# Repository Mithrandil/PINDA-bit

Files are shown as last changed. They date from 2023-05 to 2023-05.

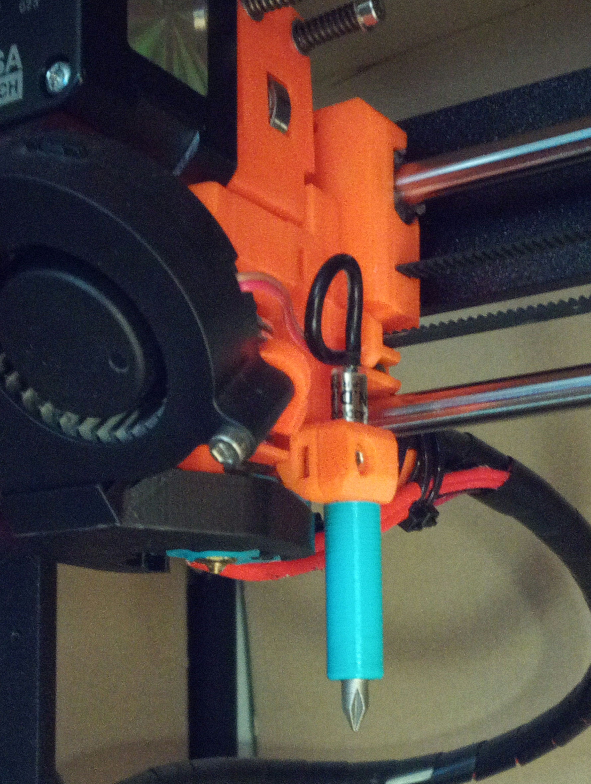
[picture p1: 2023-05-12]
PINDA-bit.jpg

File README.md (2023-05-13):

# PINDA-bit

3D Printed Bit Holder for High-Resolution Heatbed Scanning

This is a simple and useful accessory for Prusa MK2 and MK2S 3D printers (or other printers with an inductive probe). It is a plastic tube that holds a screwdriver bit and allows you to scan the MK42 heatbed with the P.I.N.D.A sensor. This way, you can level the bed for non-magnetic or off-magnet print surfaces.

The advantage of using this accessory is that you can perform finer mesh bed leveling with a 7x7 grid or any arbitrary resolution. This can improve the first layer quality and adhesion on uneven or warped beds. Moreover, since the shape of the MK42 heatbed depends only on the temperature and is consistent between prints, you don't need to scan the bed every time you change the print surface, as long as you use the same temperature. You can also save different presets of the bed mesh for different temperatures and recall them when needed.

However, to scan a print surface that is outside of the magnet points, you need to use custom firmware such as Klipper. You can find an MK2s config here: https://github.com/Mithrandil/klipper-config-prusa-mk2s

In this repository, you will find a module that corrects the tilt of the X-axis before each print. This is necessary because the position of the Z-axis motors is not preserved between prints when they are not powered. Therefore, if you use this accessory to scan a non-magnetic print surface, you need to run this module before printing to ensure a level bed.

# HOW TO USE:

The accessory is easy to use: just insert the bit into the tube and place it on the P.I.N.D.A sensor. The tube should protrude much more than the nozzle so that it can reach the print surface without touching it. Then, run a custom G-code macro to perform a mesh bed leveling with your desired resolution. You can save the mesh in your configuration file for future prints (after removing the tube).

G-Code macro for scanning and saving the high-resolution bed mesh with the accessory at a given temperature:

For 60°C heated bed (accessory mounted):

CREATE_AND_SAVE_NEW_MESH S60; [60 = first_layer_bed_temperature]

For using the saved mesh corrected with a new one (before each print, no accessory mounted):

BED_MESH_CALIBRATE; mesh bed leveling

BED_TILT_CORRECTION SAVEDMESH=MESH60; [60 = first_layer_bed_temperature]

The accessory is also easy to print: it doesn't require any supports or infill, and it takes less than 10 minutes to print. You should use a filament that can withstand high temperatures and does not deform easily, such as PETG or ASA. These filaments are especially recommended if you use an enclosure for your printer.

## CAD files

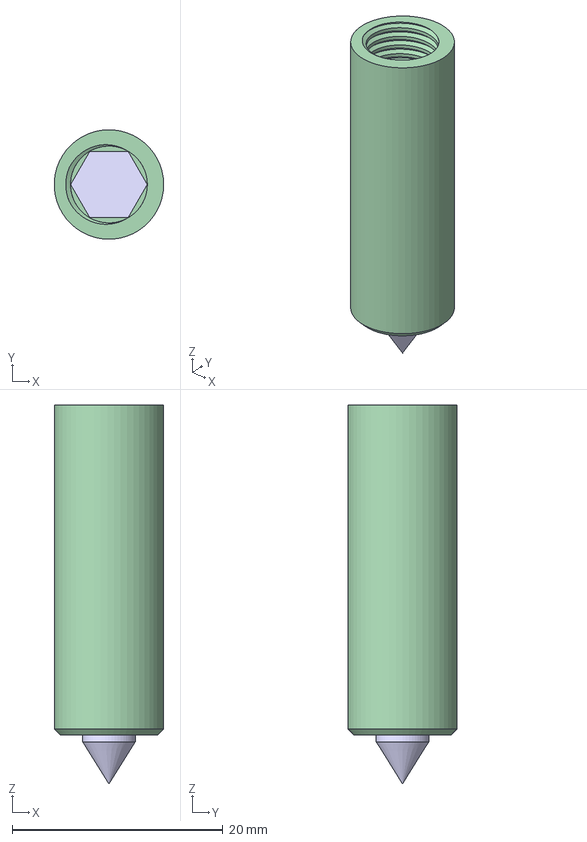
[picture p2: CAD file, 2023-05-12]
PINDA-bit.FCStd
10.4 x 10.4 x 36.0 mm
Punta-CR-VPH1
Supporto

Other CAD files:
PINDA-bit.stl

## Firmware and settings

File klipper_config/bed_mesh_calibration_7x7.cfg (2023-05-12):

[profile_manager_tilt]

[gcode_macro LOAD_AND_CORRECT_MESH]
gcode:
  {% set S = params.S|default(85)|int %}
  M140 S{S} ; set bed temp
  M190 S{S} ; wait for bed temp
  M117 Wait 2min BedWarping
  G4 P120000; wait for 2 minutes
  BED_MESH_CLEAR
  G28
  BED_MESH_CALIBRATE
  BED_TILT_CORRECTION SAVEDMESH=MESH{S}
  M140 S0 ; set bed temp

[gcode_macro CREATE_AND_SAVE_NEW_MESH]
gcode:
  {% set max_x = printer.toolhead.axis_maximum.x-1|float %}
  {% set max_y = printer.toolhead.axis_maximum.y-1|float %}
  {% set max_z = printer.toolhead.axis_maximum.z-30|float %}
  {% set S = params.S|default(85)|int %}
  M140 S{S} ; set bed temp
  M117 Attach BIT and WAIT
  M990190 S{S} ; wait for bed temp
  G4 P120000; wait for 2 minutes
  FORCE_MOVE STEPPER=stepper_z Distance=10 Velocity=0.5
  FORCE_MOVE STEPPER=stepper_z Distance=-10 Velocity=10
  BED_MESH_CLEAR
  G28
  BED_MESH_CALIBRATE PROFILE=MESH{S} METHOD=automatic MESH_MIN=35,6 MESH_MAX=238,202 PROBE_COUNT=7,7 ALGORITHM=bicubic
  G90
  G1 X{max_x} Y{max_y} Z{max_z}
  G4
  M84
  SAVE_CONFIG

[gcode_macro SCAN_BED]
gcode:
  {% set max_x = printer.toolhead.axis_maximum.x-1|float %}
  {% set max_y = printer.toolhead.axis_maximum.y-1|float %}
  {% set max_z = printer.toolhead.axis_maximum.z-30|float %}
  {% set S = params.S|default(85)|int %}
  M140 S{S} ; set bed temp
  M117 Attach BIT and WAIT
  M990190 S{S} ; wait for bed temp
  G4 P120000; wait for 2 minutes
  FORCE_MOVE STEPPER=stepper_z Distance=10 Velocity=0.5
  FORCE_MOVE STEPPER=stepper_z Distance=-10 Velocity=10
  BED_MESH_CLEAR
  G28
  BED_MESH_CALIBRATE PROFILE=CHECK{S} METHOD=automatic MESH_MIN=35,6 MESH_MAX=238,202 PROBE_COUNT=7,7 ALGORITHM=bicubic
  M140 S0
  G90
  G1 X{max_x} Y{max_y} Z{max_z}
  G4
  M84

[gcode_macro SCAN_BED_REPEAT]
gcode:
  {% set max_x = printer.toolhead.axis_maximum.x-1|float %}
  {% set max_y = printer.toolhead.axis_maximum.y-1|float %}
  {% set max_z = printer.toolhead.axis_maximum.z-30|float %}
  {% set S = params.S|default(85)|int %}
  {% set P = params.P|default(10)|int %}
  M140 S{S} ; set bed temp
  M117 Attach BIT and WAIT
  M990190 S{S} ; wait for bed temp
  G4 P120000; wait for 2 minutes
  FORCE_MOVE STEPPER=stepper_z Distance=10 Velocity=0.5
  FORCE_MOVE STEPPER=stepper_z Distance=-10 Velocity=10
  {% for i in range(P) %}
    BED_MESH_CLEAR
    G28
    BED_MESH_CALIBRATE PROFILE=REPEAT{i}_{S} METHOD=automatic MESH_MIN=35,6 MESH_MAX=238,202 PROBE_COUNT=7,7 ALGORITHM=bicubic
    G1 X{max_x} Y{max_y} Z{max_z}
    G4
  {% endfor %}
  M140 S0 ; set bed temp
  SAVE_CONFIG

[gcode_macro SCAN_BED_REPEAT_MOTOR_POWEROFF]
gcode:
  {% set max_x = printer.toolhead.axis_maximum.x-1|float %}
  {% set max_y = printer.toolhead.axis_maximum.y-1|float %}
  {% set max_z = printer.toolhead.axis_maximum.z-30|float %}
  {% set S = params.S|default(85)|int %}
  {% set P = params.P|default(10)|int %}
  M140 S{S} ; set bed temp
  M117 Attach BIT and WAIT
  M990190 S{S} ; wait for bed temp
  G4 P120000; wait for 2 minutes
  FORCE_MOVE STEPPER=stepper_z Distance=10 Velocity=0.5
  FORCE_MOVE STEPPER=stepper_z Distance=-10 Velocity=10
  {% for i in range(P) %}
    BED_MESH_CLEAR
    G28
    BED_MESH_CALIBRATE PROFILE=REPEAT{i}_{S} METHOD=automatic MESH_MIN=35,6 MESH_MAX=238,202 PROBE_COUNT=7,7 ALGORITHM=bicubic
    G1 X{max_x} Y{max_y} Z{max_z}
    G4
    M84
    G4 P3000; wait for 3sec
  {% endfor %}
  M140 S0 ; set bed temp
  SAVE_CONFIG

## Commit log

2023-05-12 3D files uploaded
    [PINDA-bit.FCStd, PINDA-bit.stl]
2023-05-12 klipper modules uploaded
    [bed_mesh_calibration_7x7.cfg]
2024-02-25 Update profile_manager_tilt.py
    Updated for Klipper 0.12
2025-02-09 Delete klippy/modules directory
    Updated for the new version of klipper (0.12.0)
2025-02-09 Updated to work on klipper 0.12.0
